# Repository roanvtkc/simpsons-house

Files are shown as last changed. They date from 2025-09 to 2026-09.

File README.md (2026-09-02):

# 🏠 Simpson's House Smart Home Control

A comprehensive smart home automation project that allows you to control LEDs and servo-driven garage and front doors on a Raspberry Pi directly from an iOS Swift Playgrounds app using **MQTT over WebSocket**.







<p align="center">
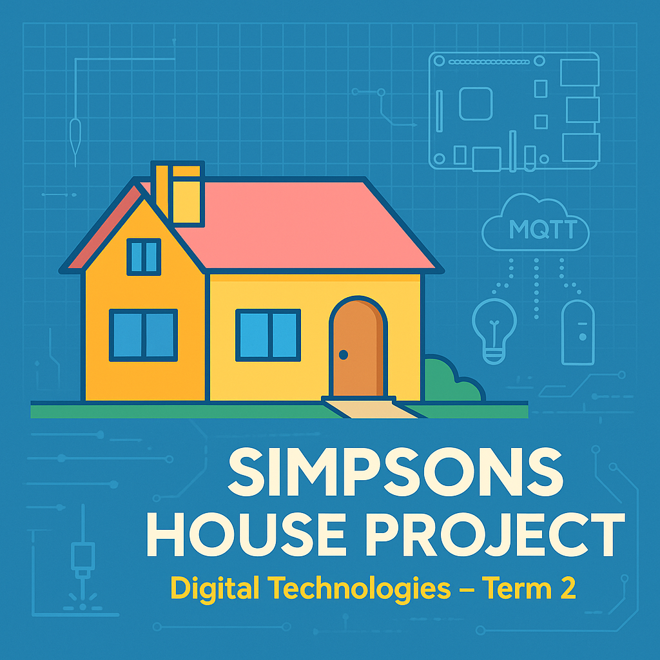
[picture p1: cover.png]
Simpsons House Project
  
</p>

## ✨ Features

- **🏠 Smart Home Control**: Complete home automation system inspired by The Simpsons
- **📱 iOS App**: Beautiful SwiftUI interface built for Swift Playgrounds
- **🌐 MQTT over WebSocket**: Modern, reliable communication protocol
- **🔧 GPIO Control**: Direct hardware control of LEDs and servo motors
- **⚙️ Servo Control**: PWM angle control on both the garage door and the front door
- **📡 Real-time Communication**: Instant response and status feedback
- **🔄 Auto-reconnection**: Robust connection handling with keep-alive pings
- **🕵️ mDNS Discovery**: Automatic network device discovery
- **⚙️ Systemd Integration**: Professional service management

## 📚 Guides

| Guide | What it covers |
|---|---|
| [WIRING_GUIDE.md](WIRING_GUIDE.md) | Identifying each component, breadboard layout, per-device troubleshooting |
| [SERVO_TUNING_GUIDE.md](SERVO_TUNING_GUIDE.md) | Changing how far the doors open, reversing direction, slowing the movement |
| [EXTENSION_GUIDE.md](EXTENSION_GUIDE.md) | Adding your own circuits — the Python side and the Swift app side |
| [TEACHING_GUIDE.md](TEACHING_GUIDE.md) | How a tap on the iPad becomes movement on the Pi |
| [laser-cut/README.md](laser-cut/README.md) | DXF sheets, part chart, layer settings |

## 🔥 Laser-cut plans

Ready-to-import DXF plans are available for two or ten houses on a 450 × 450 mm
bed, plus a ten-house 600 × 450 mm option. See the
[laser-cut guide](laser-cut/README.md) for the sheet files, previews, part chart,
layer settings, and verification results.

## 🏗️ System Architecture

```mermaid
graph TD
    A[iOS Swift Playgrounds App] -->|WebSocket| B[Mosquitto MQTT Broker]
    B -->|TCP| C[Python MQTT Listener]
    C -->|GPIO| D[Raspberry Pi Hardware]
    
    D --> E[💡 Living Room Light<br/>GPIO 17]
    D --> F[🚗 Garage Door Servo<br/>GPIO 27]
    D --> G[🚪 Front Door Servo<br/>GPIO 23]
```

## 📋 Prerequisites

- **Raspberry Pi** running Raspberry Pi OS (32-bit or 64-bit)
- **SSH access** to the Pi (default credentials: `pi`/`tkcraspberry`)
  > 📱 **iPad SSH client**: We recommend [**Secure ShellFish**](https://secureshellfish.app) — no account required, saves sessions, and has a proper iOS keyboard toolbar. Free tier is sufficient for this project.
- **Git installed** on the Pi (will be installed automatically if missing)
- **iOS device** with Swift Playgrounds 4+ or macOS with Xcode 13+
- **Hardware components**: LEDs, resistors, two SG90 servo motors (garage door and front door), breadboard
- **Same network**: Both devices must be on the same local network

## 🚀 Quick Start

### 0. Certificate Installation (Corporate Networks Only)

If you're in a corporate environment with FortiGate firewalls or other SSL inspection systems, `setup.sh` will fail at the "Upgrading pip and setuptools" step with certificate errors like:

```
ERROR: Could not find a version that satisfies the requirement setuptools (from versions: none)
ERROR: No matching distribution found for setuptools
```

with `SSLError(SSLCertVerificationError(... self-signed certificate in certificate chain))` above it in `/tmp/simpsons_house_debug.log`.

**Quick Certificate Installation:**
```bash
# Run the certificate installer from this repo
chmod +x install_ca.sh
./install_ca.sh
```

> **Note:** run the copy in this repo. A copy is also published at
> `http://10.20.1.83:8081/install_ca.sh`, but it may lag behind this one.

The installer adds the FortiGate SSL-inspection CA (`O=Fortinet`) to the system
trust store. Note that `git clone` from GitHub works *without* this — github.com
is exempt from deep inspection — so a successful clone is not evidence that the
certificate is installed. The Python package indexes (pypi.org, piwheels.org,
files.pythonhosted.org) *are* inspected, which is why `setup.sh` fails without it.

### 1. Hardware Setup

#### 🔌 GPIO Pin Layout (BCM Numbering)

```
    3V3  (1) (2)  5V
  GPIO2  (3) (4)  5V
  GPIO3  (5) (6)  GND
  GPIO4  (7) (8)  GPIO14
    GND  (9) (10) GPIO15
 GPIO17 (11) (12) GPIO18
 GPIO27 (13) (14) GND
 GPIO22 (15) (16) GPIO23
    3V3 (17) (18) GPIO24
 GPIO10 (19) (20) GND
  GPIO9 (21) (22) GPIO25
 GPIO11 (23) (24) GPIO8
    GND (25) (26) GPIO7
  GPIO0 (27) (28) GPIO1
  GPIO5 (29) (30) GND
  GPIO6 (31) (32) GPIO12
 GPIO13 (33) (34) GND
 GPIO19 (35) (36) GPIO16
 GPIO26 (37) (38) GPIO20
    GND (39) (40) GPIO21
```

#### 🔧 Wiring

> 📖 **See [WIRING_GUIDE.md](WIRING_GUIDE.md) for the full step-by-step wiring instructions**, including how to identify each component, breadboard layouts, common mistakes, and per-device troubleshooting.

Quick reference — connections at a glance:

**💡 Living Room Light (GPIO 17 → physical pin 11)**
```
Pi GPIO 17 (pin 11) ─── 220Ω resistor ─── LED (+) long leg
                                           LED (−) short leg ─── Pi GND (pin 9)
```
Key fact: the **longer LED leg is +**; it goes toward GPIO 17. The shorter leg goes to GND.

**🚗 Garage Door — Servo Motor (GPIO 27 → physical pin 13)**
```
Pi GPIO 27 (pin 13) ─── Servo SIGNAL wire (orange / yellow / white)
Pi 5V      (pin  2) ─── Servo POWER wire  (red)
Pi GND     (pin 14) ─── Servo GROUND wire (brown / black)
```
Key fact: **red is always power**; if your servo has different colours, red is still VCC.

**🚪 Front Door — Servo Motor (GPIO 23 → physical pin 16)**
```
Pi GPIO 23 (pin 16) ─── Servo SIGNAL wire (orange / yellow / white)
Pi 5V      (pin  4) ─── Servo POWER wire  (red)
Pi GND     (pin  6) ─── Servo GROUND wire (brown / black)
```
Key fact: **red is always power**; if your servo has different colours, red is still VCC.

#### 📋 Component List

| Component | Quantity | Notes |
|---|---|---|
| LED (any color) | 1 | For light indication |
| 220Ω Resistor | 1 | For LED current limiting |
| Servo Motor (SG90) | 2 | One for the garage door, one for the front door |
| Breadboard | 1 | For prototyping |
| Jumper Wires | 15+ | Male-to-female recommended |
| Breadboard Power Module | 1 | Optional, for cleaner power distribution |

#### ⚠️ Safety Notes

- **Two SG90 servos run fine on Pi 5V**: they draw little enough current that no external supply or driver board is needed
- **Never use Pi power for high-current motors**
- **Double-check connections** before powering on
- **Use appropriate resistors** to prevent LED burnout
- **Servo direction**: check which way each servo swings before gluing it into the model
- **Common Ground**: if you do add external power, its GND must be connected to Pi GND

#### 🔍 Pin Verification

Use this command to see the physical pin layout:
```bash
pinout
```

### 2. Raspberry Pi Setup

**Install Git (if needed):**

On your Raspberry Pi, if you see `git: command not found` when trying to clone:
```bash
sudo apt update
sudo apt install -y git
```

**Clone the repository:**
```bash
git clone https://github.com/roanvtkc/simpsons-house.git
cd simpsons-house
```

**Run the automated setup:**
```bash
chmod +x setup.sh
./setup.sh
```

The setup script will:
- ✅ Install all required packages (including git if missing)
- ✅ Configure MQTT with WebSocket support (ports 1883 and 9001)
- ✅ Set up Python environment and GPIO control
- ✅ Create systemd services for automatic startup
- ✅ Configure mDNS for device discovery
- ✅ Test all components

### 3. iOS App Setup

1. **Open Swift Playgrounds** on your iOS device
2. **Create a new playground** or import the provided Swift package
3. **Copy the Simpson's House app code** into your playground
4. **Update the IP address** if needed (the app defaults to `192.168.5.115`)
5. **Run the app** and grant Local Network permissions when prompted

## 🎮 Using the App

### Connection
1. **Tap "Connect to House"** to establish MQTT over WebSocket connection
2. **Wait for "🏠 Simpson's House Connected!"** status
3. **Start controlling your devices!**

### Device Controls
- **💡 Living Room Light**: Toggle the main lighting
- **🚗 Garage Door**: Open and close using the garage servo
  - `OPEN`: Drive the servo to the open angle
  - `CLOSE`: Drive the servo to the closed angle
  - Tuning these angles: see [SERVO_TUNING_GUIDE.md](SERVO_TUNING_GUIDE.md)
- **🚪 Front Door**: Operate the servo-controlled entrance

### Features
- **📊 Real-time status**: See device states instantly
- **📋 Activity logs**: Monitor all commands and responses
- **ℹ️ System info**: View hardware and network configuration
- **🔄 Auto-reconnect**: Automatic connection recovery

## 🛠️ Configuration

### MQTT Topics
| Topic | Description | Commands |
|---|---|---|
| `home/light` | Living room light control | `ON`, `OFF` |
| `home/garage` | garage door servo (GPIO 27) | `OPEN`, `CLOSE` |
| `home/door` | Front door servo | `ON` (open), `OFF` (close) |

### Network Ports
- **1883**: MQTT TCP (standard MQTT clients)
- **9001**: MQTT WebSocket (iOS app)

### Service Management
```bash
# Check status
sudo systemctl status simpsons-house
sudo systemctl status mosquitto

# View logs
sudo journalctl -u simpsons-house -f
sudo journalctl -u mosquitto -f

# Restart services
sudo systemctl restart simpsons-house
sudo systemctl restart mosquitto

# Test MQTT manually
mosquitto_pub -h localhost -t home/light -m ON
mosquitto_pub -h localhost -t home/garage -m OPEN
mosquitto_sub -h localhost -t home/# -v
```

## 🔧 Advanced Configuration

### Custom GPIO Pins
Edit `mqttlistener.py` to change pin assignments:
```python
# GPIO pin assignments (BCM numbering)
LIGHT_PIN        = 17   # Light control
GARAGE_SERVO_PIN = 27   # Garage door servo signal
SERVO_PIN        = 23   # Front door servo signal
```

### Servo Angles
The front door and garage door angles are set in `control_door()` and `control_garage_door()` in `mqttlistener.py`:
```python
angle = 90 if state else 0   # OPEN = 90°, CLOSED = 0°
```

> 📖 **See [SERVO_TUNING_GUIDE.md](SERVO_TUNING_GUIDE.md)** for how to find the right angles for your model, reverse a door's direction, and slow the movement down — plus `servo_calibrate.py`, an interactive tool for jogging each servo to find its angles.

### Network Settings
Update the iOS app host address:
```swift
@StateObject private var mqttClient = SimpsonsHouseMQTTClient(host: "YOUR_PI_IP_ADDRESS")
```

## 🧪 Testing & Verification

### Test GPIO Pins Before MQTT Setup

**Run the built-in hardware test:**
```bash
cd ~/simpsons-house
python3 gpio_test.py
```

It walks the light and both servos in turn. If you want to try a single servo by
hand, this is the minimum:
```python
#!/usr/bin/env python3
import RPi.GPIO as GPIO
import time

GARAGE_SERVO_PIN = 27          # use 23 for the front door servo

GPIO.setmode(GPIO.BCM)
GPIO.setup(GARAGE_SERVO_PIN, GPIO.OUT)
pwm = GPIO.PWM(GARAGE_SERVO_PIN, 50)   # 50 Hz is the hobby-servo standard
pwm.start(0)

try:
    for angle in (0, 90, 0):
        pwm.ChangeDutyCycle((angle / 180.0) * 10 + 2)   # 0° → 2%, 180° → 12%
        time.sleep(0.8)                                  # let the servo travel
        pwm.ChangeDutyCycle(0)                           # stop pulsing, avoid jitter
        time.sleep(0.5)
finally:
    pwm.stop()
    GPIO.cleanup()
```

### Expected Results:
- **💡 Light LED**: Should turn ON for 2 seconds, then OFF
- **🚗 Garage door servo**: Should swing from 0° (closed) to 90° (open) and back
- **🚪 Front door servo**: Should move from 0° to 90° and back to 0°

### Verify Services
```bash
# Check MQTT broker
sudo systemctl status mosquitto

# Check listening ports (should show both 1883 and 9001)
sudo netstat -tlnp | grep -E "(1883|9001)"

# Test MQTT broker
mosquitto_pub -h localhost -t test/message -m "Hello Simpson's House"
mosquitto_sub -h localhost -t test/# -v

# Check mDNS discovery
avahi-browse -rt _mqtt._tcp
```

### Test Device Control
```bash
# Test individual devices
mosquitto_pub -h localhost -t home/light -m ON
mosquitto_pub -h localhost -t home/garage -m OPEN   # Open garage door
mosquitto_pub -h localhost -t home/garage -m CLOSE  # Close garage door
mosquitto_pub -h localhost -t home/door -m ON   # Servo open
```

## 🐛 Troubleshooting

<details>
<summary><strong>Servo Motor Issues</strong></summary>

**Servo doesn't move:**
- Check the signal wire is on the right pin — GPIO 27 (pin 13) for the garage, GPIO 23 (pin 16) for the front door
- Red wire must be on Pi 5V, not 3.3V — a servo on 3.3V often twitches but won't hold
- Ensure the servo GND is connected to Pi GND
- Confirm nothing else is holding the pin: `sudo fuser /dev/gpiomem`

**Servo jitters or hums when idle:**
- Expected if pulses keep being sent. The code calls `ChangeDutyCycle(0)` after each move to stop this — check it isn't commented out
- Both servos on Pi 5V can brown out the Pi if they move at the same instant under load; add an external 5V supply (GND common with the Pi) if so

**Servo moves the wrong way:**
- Swap the angles in `control_garage_door()` / `control_door()` — the code maps OPEN = 90°, CLOSED = 0°
- Or remount the horn 90° round on the spline

**Servo doesn't reach full travel:**
- SG90s vary; adjust the 2%–12% duty range in `set_servo_angle()` to suit your unit
- Check the door isn't binding on the model before blaming the servo
</details>

<details>
<summary><strong>GPIO & Hardware Issues</strong></summary>

**Check GPIO status:**
```bash
# See pin layout
pinout

# Check what's using GPIO pins
sudo fuser /dev/gpiomem
```

**Manual servo testing:**

A servo needs a continuous 50 Hz pulse train, so it cannot be driven from the
shell the way an LED can — use the Python snippet in
[Testing & Verification](#-testing--verification) above, or `gpio_test.py`.

**Common servo wiring issues:**
- Signal on the wrong pin: garage is GPIO 27 (pin 13), front door is GPIO 23 (pin 16)
- Power on 3.3V instead of 5V — always use a 5V pin for the red wire
- Missing common ground between servo and Pi
- Connector reversed: check the wire colours, not the plug orientation — red is always power
</details>

### Log Locations
- **Setup logs**: `/tmp/simpsons_house_setup.log`
- **MQTT listener**: `sudo journalctl -u simpsons-house -f`
- **Mosquitto broker**: `/var/log/mosquitto/mosquitto.log`
- **System logs**: `sudo journalctl -f`

## 🔒 Security Considerations

> ⚠️ **Important**: This project uses `allow_anonymous true` for simplicity. For production use:

- Enable MQTT authentication with username/password
- Use TLS/SSL encryption for MQTT connections
- Configure firewall rules to limit access
- Regular security updates for all components
- Consider VPN access for remote control

## 📁 Project Structure

```
simpsons-house/
├── 📄 README.md                    # This file
├── 📖 SERVO_TUNING_GUIDE.md         # Adjusting door angles, direction and speed
├── 📖 EXTENSION_GUIDE.md            # Adding your own circuits (Python + Swift)
├── 🔧 setup.sh                     # Automated setup script
├── 🐍 mqttlistener.py               # Python MQTT listener with servo control
├── 🔐 install_ca.sh                # FortiGate certificate installer
├── 🧪 gpio_test.py                  # Hardware test: light + both servos
├── 🎛️  servo_calibrate.py            # Interactive servo angle finder
├── 📁 extensions/                   # Optional extension hardware
│   └── 🧪 stepper_test.py           # Stepper motor test (extension only)
├── 📱 ios-app/                     # Swift Playgrounds app code
│   └── ContentView.swift
├── 📋 systemd/                     # Systemd service files
│   └── simpsons-house.service
└── 📊 docs/                        # Additional documentation
    ├── hardware-setup.md
    ├── troubleshooting.md
    └── api-reference.md
```

## 🤝 Contributing

We welcome contributions! Please see our [Contributing Guide](CONTRIBUTING.md) for details.

### Development Setup
1. **Fork the repository**
2. **Create a feature branch**: `git checkout -b feature/amazing-feature`
3. **Commit changes**: `git commit -m 'Add amazing feature'`
4. **Push to branch**: `git push origin feature/amazing-feature`
5. **Open a Pull Request**

## 📄 License

This project is licensed under the MIT License - see the [LICENSE](LICENSE) file for details.

## 🎯 Roadmap

### Upcoming Features
- [ ] **Temperature sensors** and climate control
- [ ] **Motion detection** and security features
- [ ] **Voice control** integration (Siri Shortcuts)
- [ ] **Web dashboard** for browser control

> **Motors are extension work, not core.** DC motors, steppers, speed control and
> direction reversal all need external power and a driver board, so they sit
> outside the base build. See [EXTENSION_GUIDE.md](EXTENSION_GUIDE.md).

### Version History
- **v3.3** - Garage door moved from a 28BYJ-48 stepper + ULN2003 to an SG90 servo on GPIO 27
- **v3.1** - ULN2003 motor driver integration, improved motor control
- **v3.0** - MQTT over WebSocket support, systemd integration
- **v2.0** - Basic MQTT control with GPIO
- **v1.0** - Initial HTTP-based control system

## 📞 Support

### Getting Help
- 📖 Check the [Documentation](docs/)
- 🐛 [Report Issues](https://github.com/roanvtkc/simpsons-house/issues)
- 💬 [Discussions](https://github.com/roanvtkc/simpsons-house/discussions)
- ❓ [FAQ](docs/faq.md)

### Community
- 🌟 **Star this repo** if you find it useful!
- 🐦 Follow updates on Twitter: [@SimpsonsHousePi](https://twitter.com/simpsonshousepi)
- 💡 Share your builds and modifications

---

**Made with ❤️ for smart home enthusiasts and Simpsons fans**

For support and questions, please [open an issue](https://github.com/roanvtkc/simpsons-house/issues) or check our [troubleshooting guide](docs/troubleshooting.md).

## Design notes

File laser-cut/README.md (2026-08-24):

# Laser-cut enclosure

Cut files for the physical Simpsons House model that the Raspberry Pi hardware
goes into.

## Available layouts

| Folder | Bed/stock size | Houses | Sheets | Average utilisation |
|---|---:|---:|---:|---:|
| `sheets-450x450-two-houses/` | 450 × 450 mm | 2 | 3 | 83.6% |
| `sheets-450x450-ten-houses/` | 450 × 450 mm | 10 | 15 | 83.6% |
| `sheets-600x450/` | 600 × 450 mm | 10 | 11 | 85.5% |

The two-house layout uses the theoretical minimum of three 450 × 450 sheets:
the combined reserved part area will not fit on two sheets. The ten-house
450 × 450 layout likewise cannot fit on fewer than 15 sheets with the specified
3 mm part spacing and 5 mm border.

## What to send to the laser

For two houses on the 450 × 450 mm RedSail, send
`sheets-450x450-two-houses/sheet-01.dxf` … `sheet-03.dxf`. The files are in
millimetres.

For ten houses on the same 450 × 450 bed, send
`sheets-450x450-ten-houses/sheet-01.dxf` … `sheet-15.dxf`. If 600 × 450 stock
is available, the more compact option is `sheets-600x450/sheet-01.dxf` …
`sheet-11.dxf`.

Each file has three layers:

| Layer | What to do with it |
|---|---|
| `CUT` | Cut this. Part outlines plus the LED and access-port holes. |
| `ENGRAVE` | Part numbers, single-stroke. Run as a light score, or switch off. |
| `SHEET` | Reference rectangle matching the selected sheet size. **Not for cutting** — switch off or delete. |

**46 of 52 parts carry a number.** Each number sits on material only, at least
0.35 mm clear of every cut and score line, turned 90° where a narrow frame band
is the only place it fits. The six that are blank (31, 32, 40–43) are window
inserts whose bars are 2.5 mm wide — too narrow for a readable number. Each
belongs to a set of identical parts, so they are interchangeable; identify them
from `PART-CHART.pdf`.

## Reference

| File | Contents |
|---|---|
| `sheets-*/CUT-PLAN.txt` | Part library with sizes, and what sits on each sheet for that layout |
| `PART-CHART.pdf` | Every part drawn and numbered — use it to identify cut pieces |
| `ASSEMBLY-MAPPING.md` | Proposed mapping from engraved numbers to the assembly-instruction step numbers, graded by confidence |
| `sheets-*/nest-preview.png` | All sheets in that layout at a glance |
| `source/` | The original Shapr3D DXF export |

## LED and access-port cutouts

The original six circular cutouts are restored at their authored locations on
every house. They had appeared outside the parts because DXF stores circle
centres in object coordinates and this Shapr3D export uses a reversed normal;
the generator now converts them to world coordinates before grouping and
nesting the panels.

| Part | Circular cuts per house | Purpose |
|---:|---|---|
| 01 | 1 × 22.361 mm | Access port |
| 02 | 1 × 50.000 mm | Access port |
| 06 | 1 × 5.000 mm | LED hole |
| 08 | 1 × 36.056 mm, 2 × 5.000 mm | Access port and two LED holes |

Each generated `CUT-PLAN.txt` records the exact local position of these holes.
`PART-CHART.pdf` shows which panels contain them.

## Two-house 450 × 450 results

- 52 parts per house, 104 parts across 3 sheets
- 83.6% average sheet utilisation: 88.8%, 87.0%, and 75.0%
- 3 mm between part bounding boxes and a 5 mm border
- All 4,118 cut entities verified present, including 12 circular cutouts; no part overlaps; every part inside the margin
- All 1,292 engrave strokes verified on material and at least 0.35 mm from a cut line

## Ten-house 450 × 450 results

- 52 parts per house, 520 parts across 15 sheets
- 83.6% average sheet utilisation
- 3 mm between part bounding boxes and a 5 mm border
- All 20,590 cut entities verified present, including 60 circular cutouts
- All 6,460 engrave strokes verified on material and at least 0.35 mm from a cut line
- No part overlaps; every part is inside the margin

## Ten-house 600 × 450 results

- 52 parts per house (40 distinct shapes), 520 parts over 11 sheets
- 85.5% average sheet utilisation
- 3 mm between parts, 5 mm border
- All 20,590 cut entities verified present, including 60 circular cutouts; no part overlaps; every part inside the margin
- All 6,460 engrave strokes verified on material and at least 0.35 mm from a cut line

## Known source-export issue

There are **27 open-contour gaps**, largest 0.090 mm. They are recorded in each
`CUT-PLAN.txt` and are not changed in the cut files. Most laser software cuts
open paths fine; if yours needs closed contours, weld on import with a 0.1 mm
tolerance.

Note also that the 3 mm spacing is *between parts*, not kerf compensation — cut
paths are the original geometry, so parts finish about one kerf undersize. Check
a test joint before committing a full run of material.

## Regenerating

```bash
cd laser-cut/src
pip install -r requirements.txt
python nest.py --sheet-w 600 --sheet-h 450 --outdir ../sheets-600x450
python nest.py --copies 2 --sheet-w 450 --sheet-h 450 --outdir ../sheets-450x450-two-houses
python nest.py --copies 10 --sheet-w 450 --sheet-h 450 --outdir ../sheets-450x450-ten-houses
python chart.py --out ../PART-CHART.svg
```

`nest.py` reads `../source/Simpsons House with precuts.dxf`; override with
`SIMPSONS_DXF=/path/to/other.dxf`.

Useful flags: `--copies N` (default 10), `--gap`, `--margin`, `--no-rotate`,
`--no-engrave`, `--keep-strays` (include truly isolated circles that do not
belong to a part).

| Script | Role |
|---|---|
| `parts.py` | Reads the DXF, groups loose lines into parts by endpoint connectivity, absorbs holes |
| `labels.py` | Builds each part's solid region and finds where a number fits |
| `strokefont.py` | Single-stroke digits |
| `verify_labels.py` | Independent check that a number is on material — ray casting against the raw cut segments |
| `nest.py` | Packs parts onto sheets, verifies, writes DXFs and the cut plan |
| `check_sheets.py` | End-to-end check of the written DXFs (`python check_sheets.py ../sheets-450x450-two-houses`) |
| `chart.py` | Renders the part identification chart |
| `shapes.py` | Reports which parts are duplicates |

The source DXF has 2,053 loose `LINE` entities rather than closed polylines,
plus the six `CIRCLE` cutouts. Part identity is reconstructed from endpoint
connectivity and the contained circles are absorbed into their panels.
`nest.py` self-checks on every run: no part overlaps, everything is inside the
margin, every engraved number lands on material, and the line/circle entity
counts round-trip through the written files.

Engrave placement is checked **twice, by two independent routes**. `labels.py`
decides where a number goes from the part's solid region; `verify_labels.py`
then re-tests it by ray casting against the raw cut segments, never touching
that solid. This matters: an earlier version checked the text against the same
solid that positioned it, so when the solid was wrong the numbers landed in
window openings and the check still passed. `check_sheets.py` closes the loop by
re-deriving the material from the finished DXFs, which is the only check that
can catch a bad transform on a rotated copy.

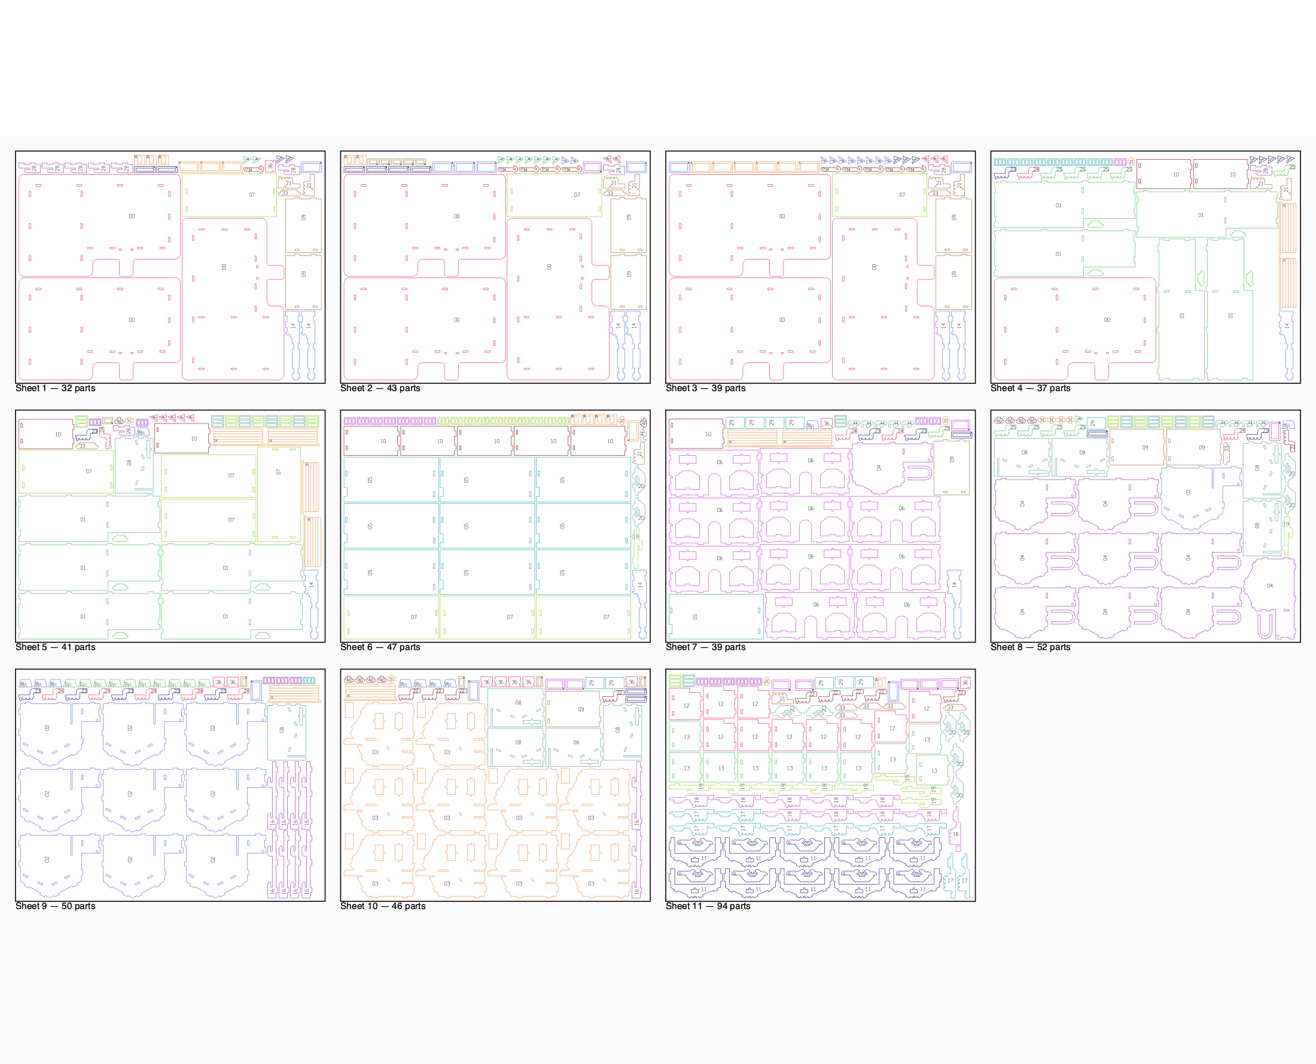
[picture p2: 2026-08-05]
laser-cut/nest-preview.png

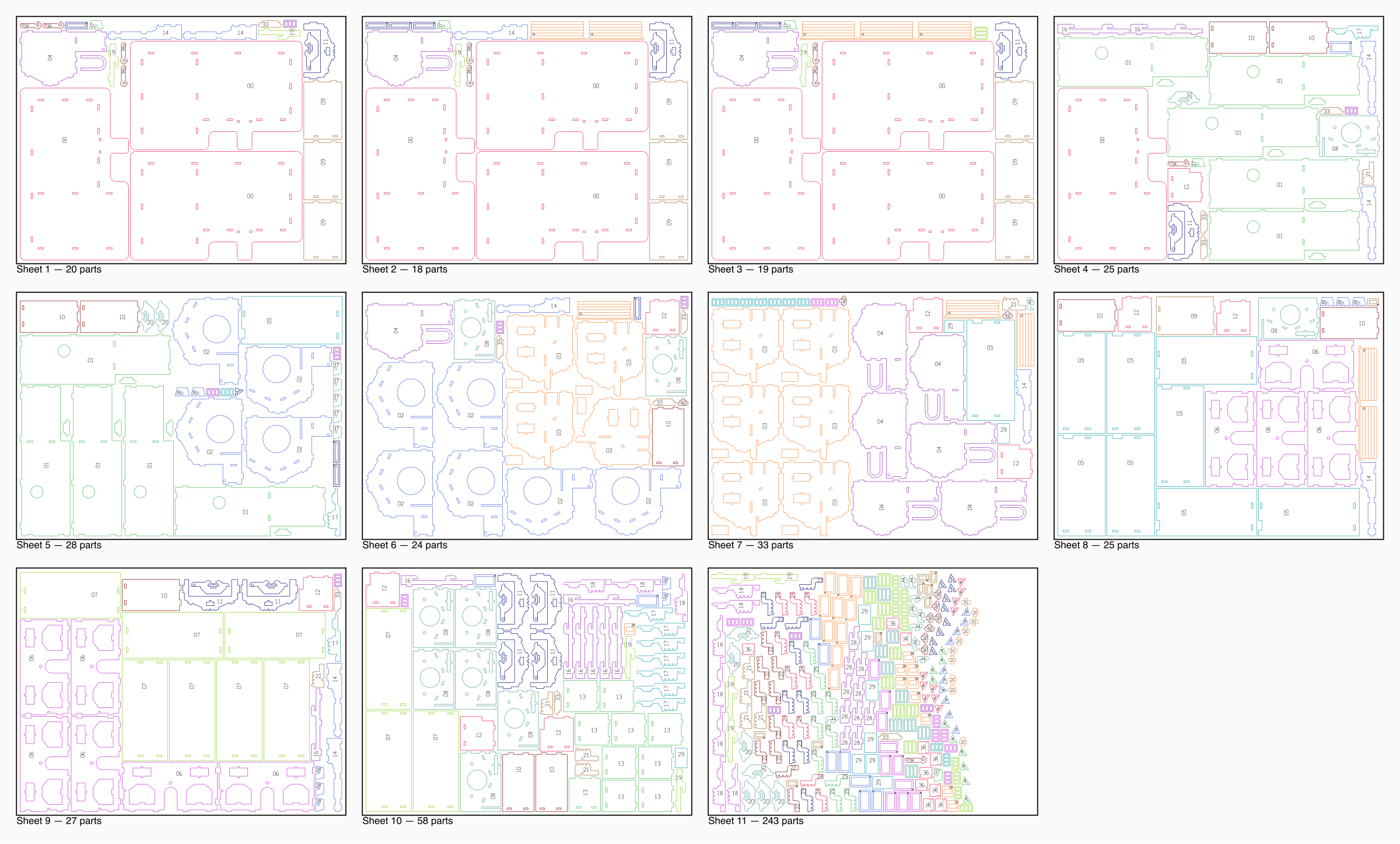
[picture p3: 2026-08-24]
laser-cut/sheets-600x450/nest-preview.png

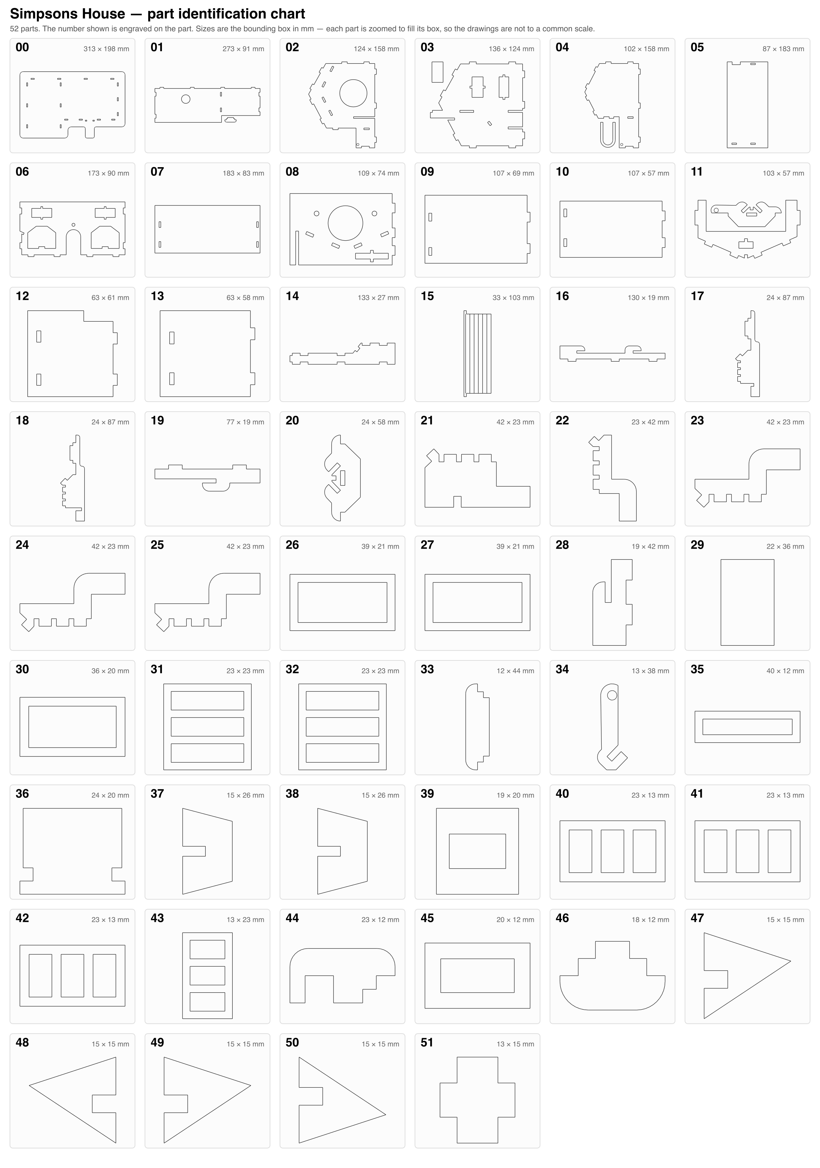
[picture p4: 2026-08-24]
laser-cut/PART-CHART.png

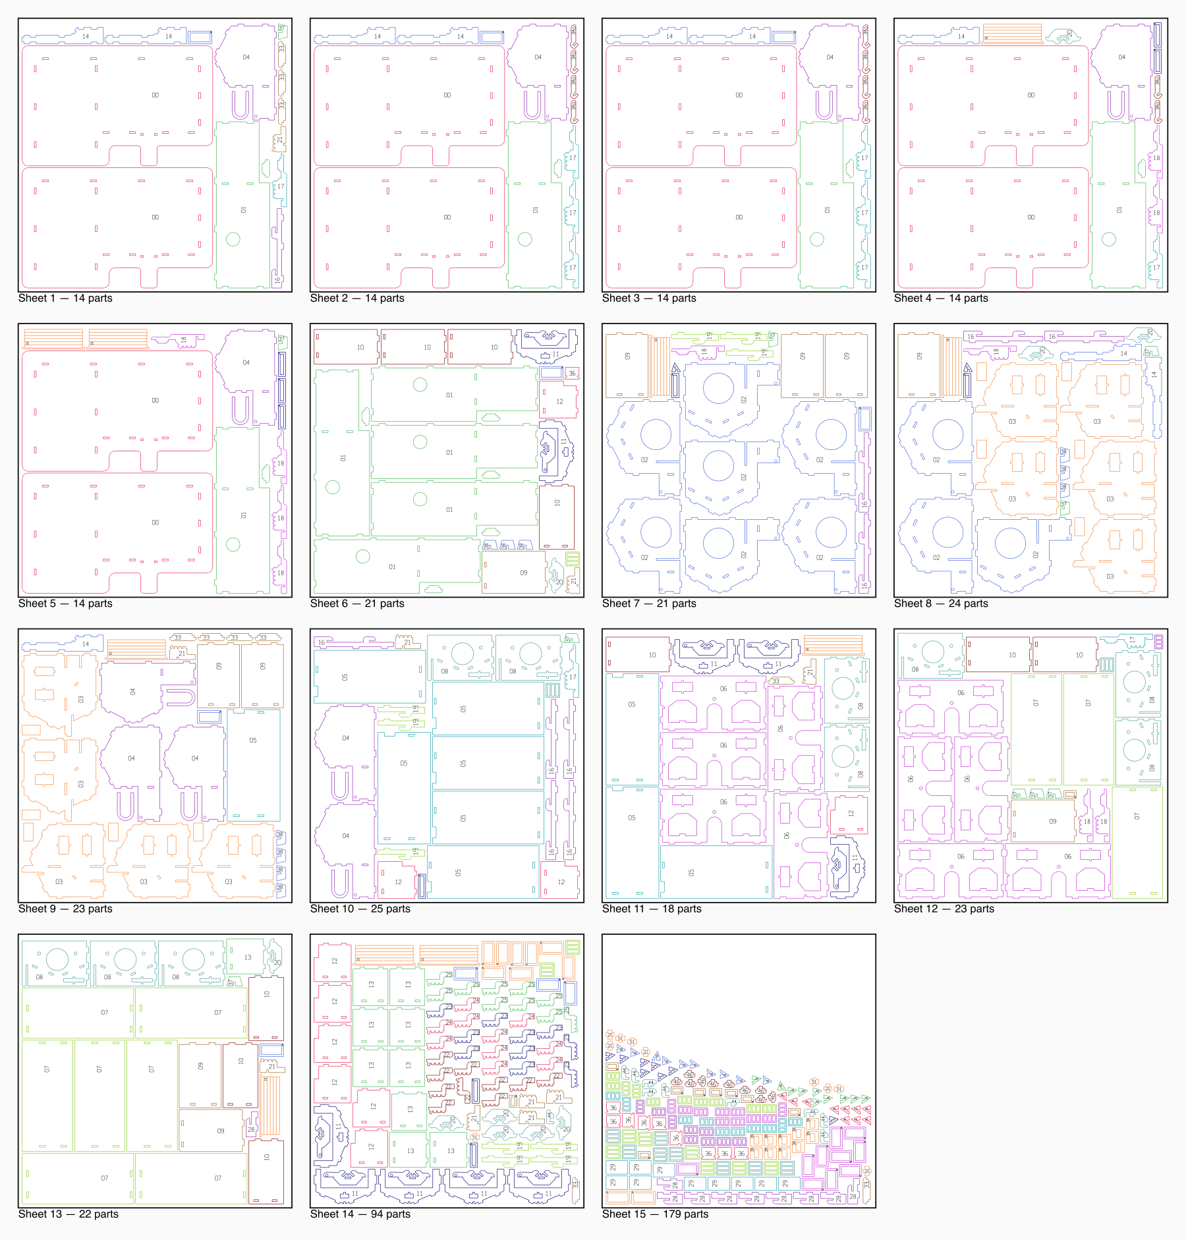
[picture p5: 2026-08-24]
laser-cut/sheets-450x450-ten-houses/nest-preview.png

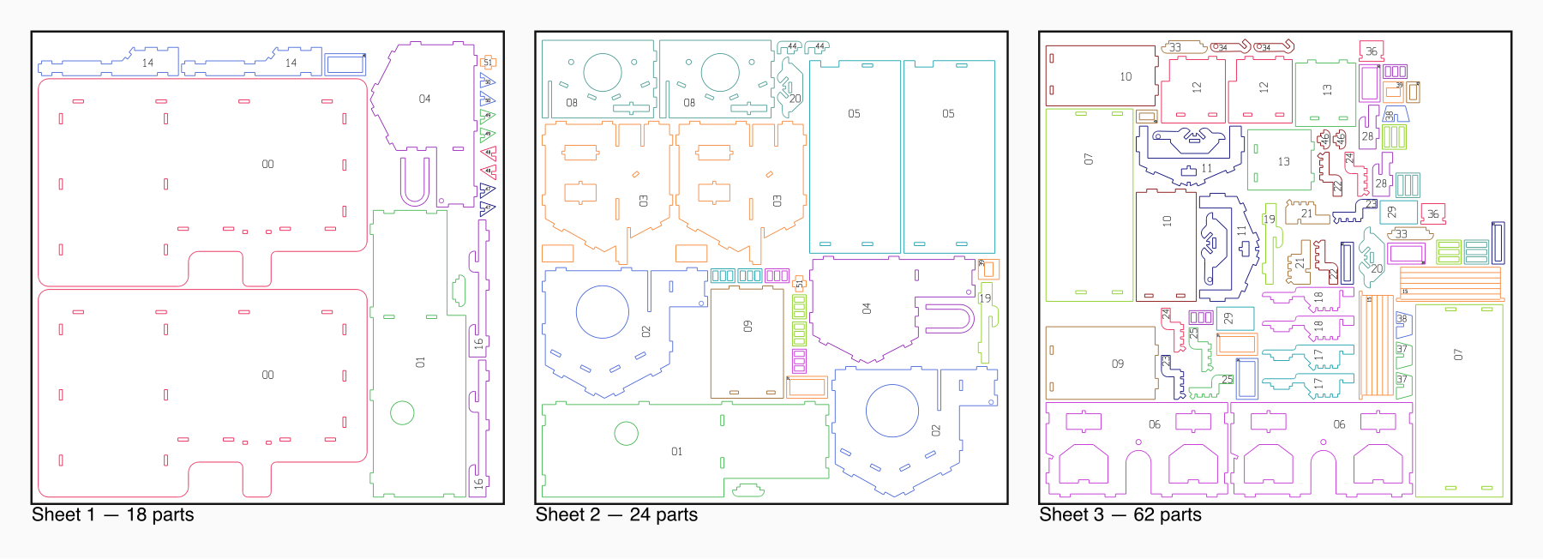
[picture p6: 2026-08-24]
laser-cut/sheets-450x450-two-houses/nest-preview.png

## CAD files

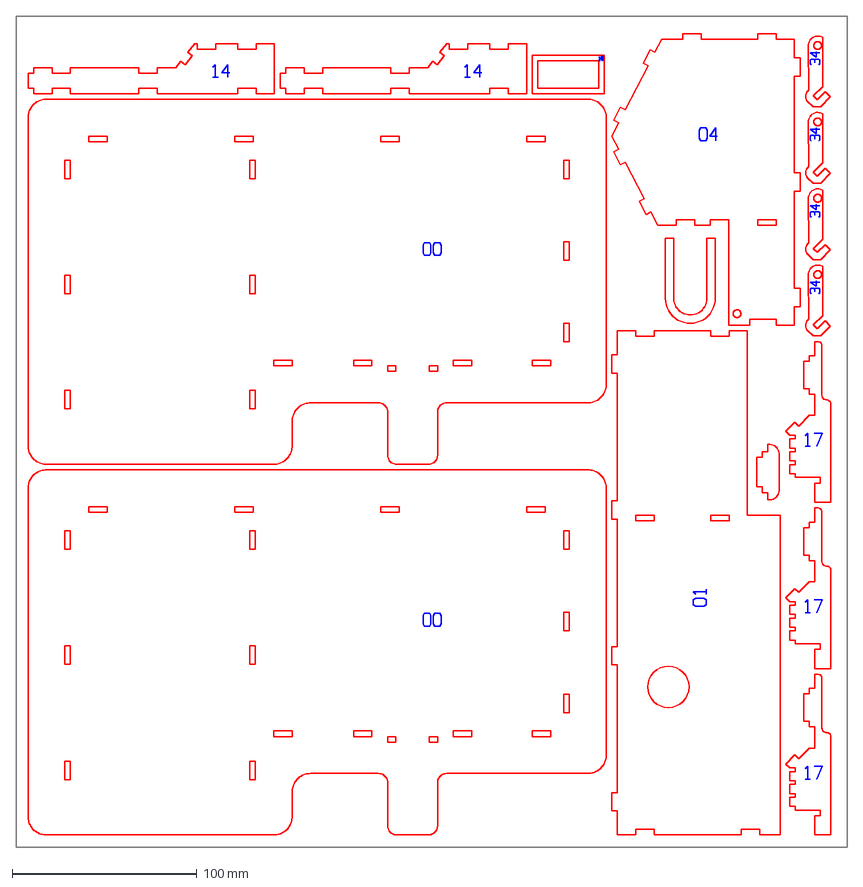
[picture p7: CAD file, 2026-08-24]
laser-cut/sheets-450x450-ten-houses/sheet-02.dxf
450.0 x 450.0 mm

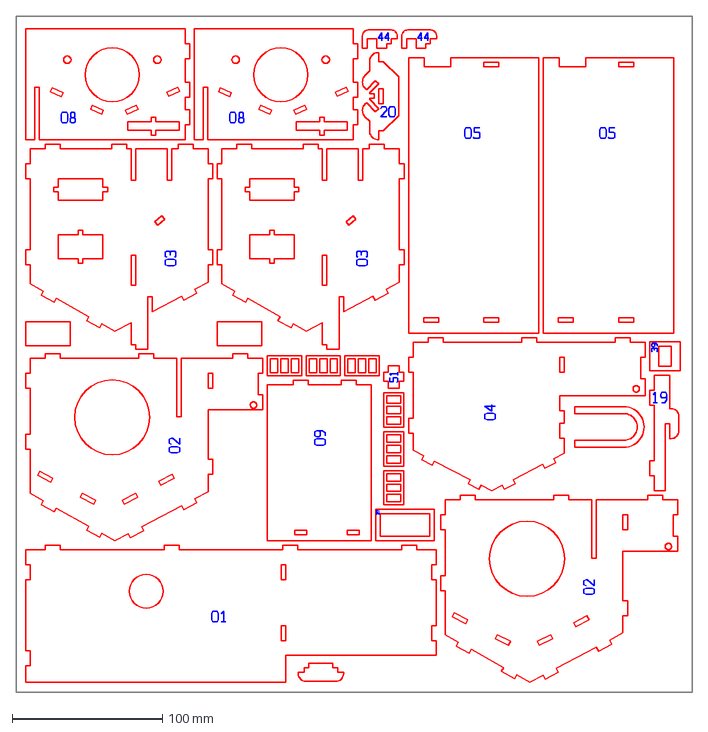
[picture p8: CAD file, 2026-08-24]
laser-cut/sheets-450x450-two-houses/sheet-02.dxf
450.0 x 450.0 mm

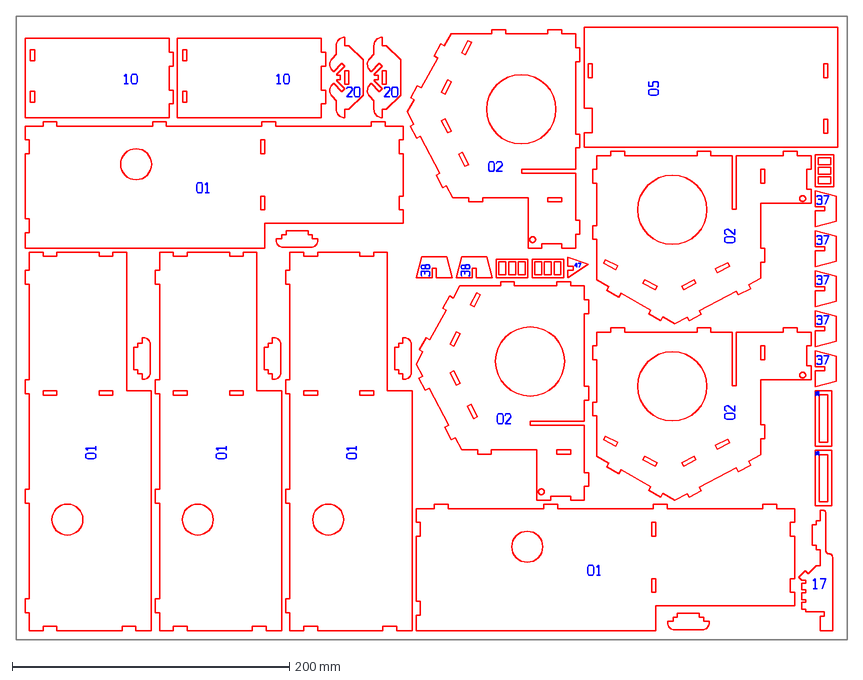
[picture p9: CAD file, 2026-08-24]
laser-cut/sheets-600x450/sheet-05.dxf
600.0 x 450.0 mm

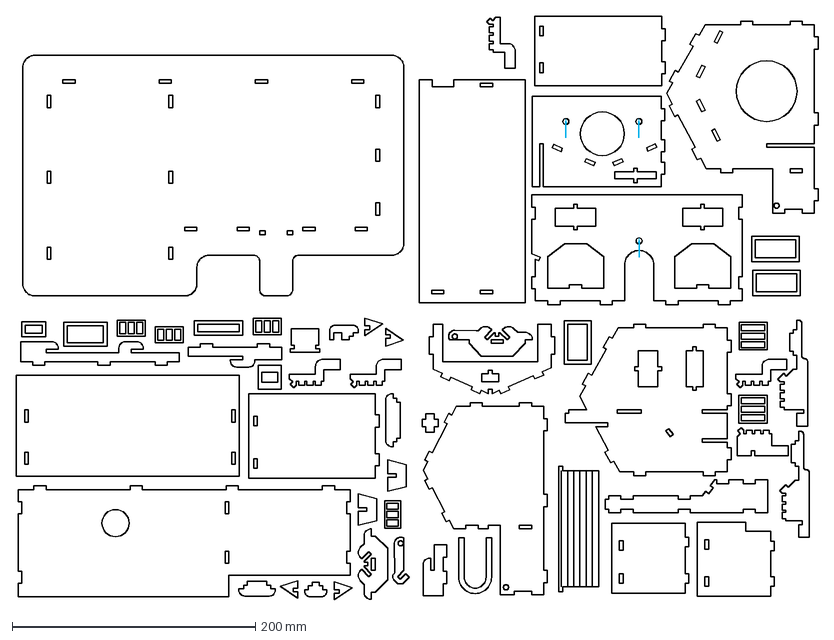
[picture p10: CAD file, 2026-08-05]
laser-cut/source/Simpsons House with precuts.dxf
659.1 x 479.4 mm

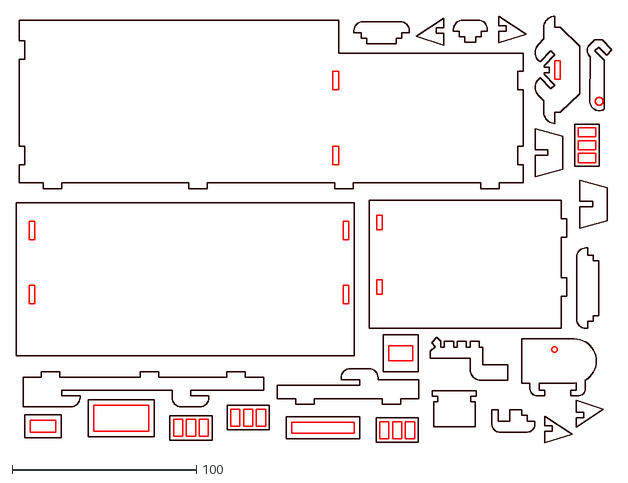
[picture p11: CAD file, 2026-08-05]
Simpson House DXF Files/Simpsons_house_02.dxf
323.0 x 231.4

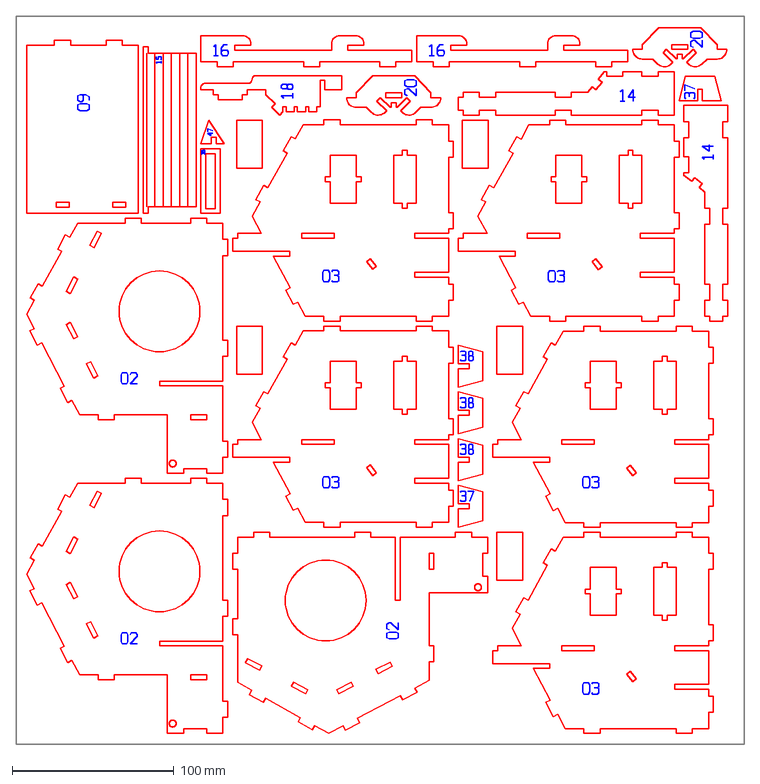
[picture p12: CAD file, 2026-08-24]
laser-cut/sheets-450x450-ten-houses/sheet-08.dxf
450.0 x 450.0 mm

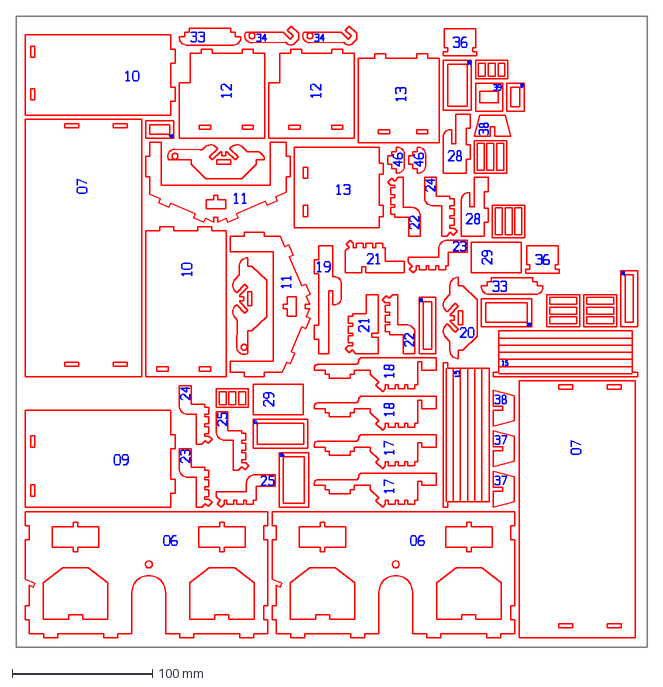
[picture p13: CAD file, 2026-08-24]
laser-cut/sheets-450x450-two-houses/sheet-03.dxf
450.0 x 450.0 mm

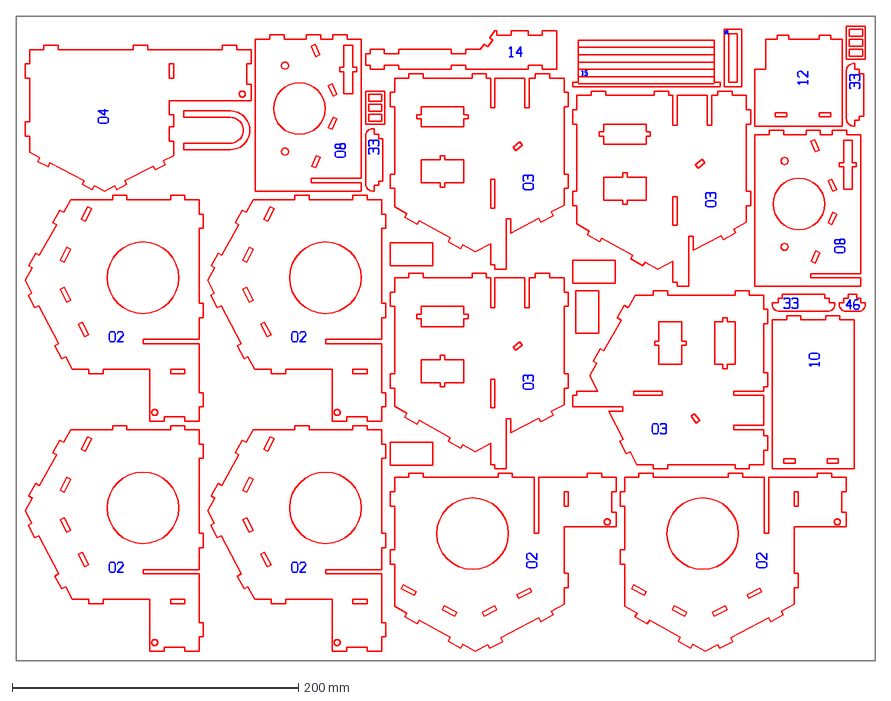
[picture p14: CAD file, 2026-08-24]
laser-cut/sheets-600x450/sheet-06.dxf
600.0 x 450.0 mm

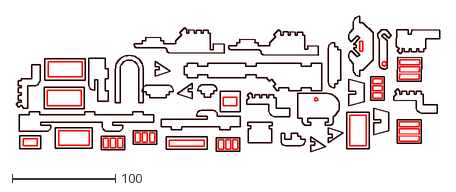
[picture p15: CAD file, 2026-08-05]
Simpson House DXF Files/Simpsons_house_small pieces.dxf
411.0 x 131.2

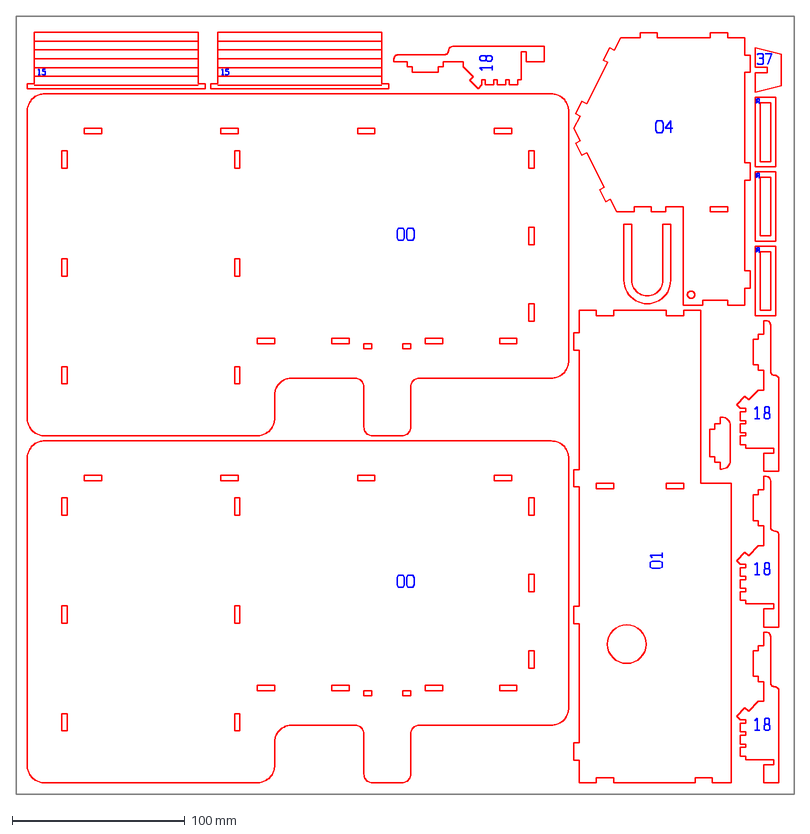
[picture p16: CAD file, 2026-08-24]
laser-cut/sheets-450x450-ten-houses/sheet-05.dxf
450.0 x 450.0 mm

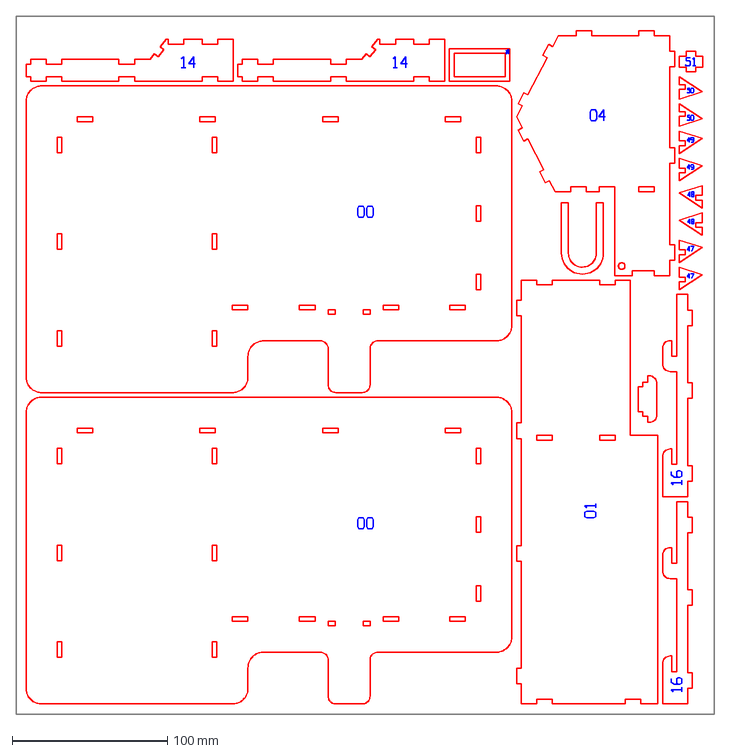
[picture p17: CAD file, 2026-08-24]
laser-cut/sheets-450x450-two-houses/sheet-01.dxf
450.0 x 450.0 mm

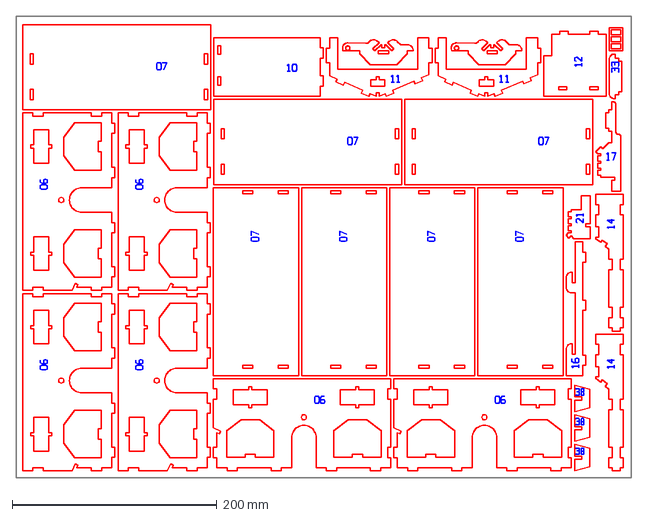
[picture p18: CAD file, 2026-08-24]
laser-cut/sheets-600x450/sheet-09.dxf
600.0 x 450.0 mm

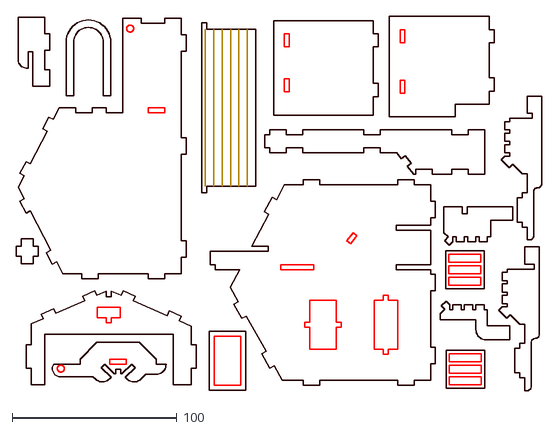
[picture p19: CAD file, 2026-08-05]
Simpson House DXF Files/Simpsons_house_01.dxf
318.3 x 226.8

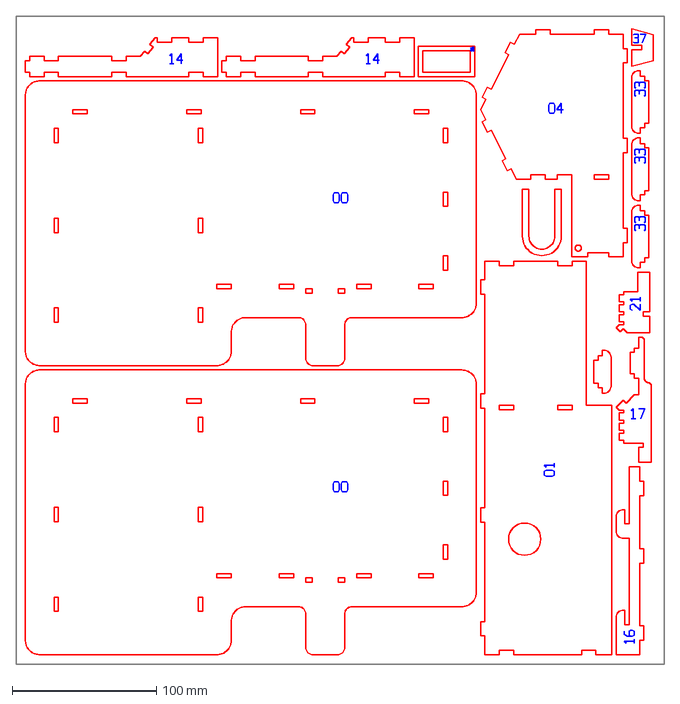
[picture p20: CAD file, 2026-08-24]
laser-cut/sheets-450x450-ten-houses/sheet-01.dxf
450.0 x 450.0 mm

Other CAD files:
Simpson House DXF Files/Whole Simpsons House v1.dxf
laser-cut/sheets-600x450/sheet-02.dxf
Simpson House DXF Files/Simpsons_house_04.dxf
laser-cut/sheets-450x450-ten-houses/sheet-15.dxf
Simpson House DXF Files/Simpsons House with precuts.dxf
Simpson House DXF Files/Simpsons_house_03.dxf
Simpson House DXF Files/Simpsons_house_small pieces.dwg
laser-cut/sheets-450x450-ten-houses/sheet-03.dxf
laser-cut/sheets-450x450-ten-houses/sheet-04.dxf
laser-cut/sheets-450x450-ten-houses/sheet-06.dxf
laser-cut/sheets-450x450-ten-houses/sheet-07.dxf
laser-cut/sheets-450x450-ten-houses/sheet-09.dxf
laser-cut/sheets-450x450-ten-houses/sheet-10.dxf
laser-cut/sheets-450x450-ten-houses/sheet-11.dxf
laser-cut/sheets-450x450-ten-houses/sheet-12.dxf
laser-cut/sheets-450x450-ten-houses/sheet-13.dxf
laser-cut/sheets-450x450-ten-houses/sheet-14.dxf
laser-cut/sheets-600x450/sheet-01.dxf
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

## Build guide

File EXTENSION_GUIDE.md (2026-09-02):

# Extension Guide — Adding Your Own Circuits

For students who have the light, garage door and front door working, and want
to add something of their own.

You will add one new device end to end: a physical component on the
breadboard, a control function on the Raspberry Pi, and a button in the iPad
app.

---

## Safety first

- **Low voltage only.** Everything in this project runs on 3.3V or 5V from the
  Pi. Never wire anything to mains power. If your idea needs mains, it does not
  go in this project.
- **Power the Pi off** before adding or moving any wire.
- **Check the current.** A single GPIO pin can supply about 16 mA safely, and
  the whole chip about 50 mA total. An LED is fine. A motor is not — it needs
  its own power supply and a transistor or driver board.
- If anything gets hot or smells, unplug it immediately.

---

## How a device is wired into the software

Every device already in this project exists in **eight places**. Adding one
means repeating that same pattern. Nothing here is clever — it is the same
five lines copied and renamed.

```
   iPad app                                Raspberry Pi
   ─────────                               ────────────
   1. DeviceStates property   ──┐
   2. topics list               │   MQTT     ┌── 5. TOPIC_ constant
   3. toggle function        ───┼──────────▶ ├── 6. device_states entry
   4. card in the grid          │            ├── 7. control function
                                │            └── 8. branch in on_message()
                                │                     │
                                └──── status ◀────────┘
```

Plus one on the hardware side: **the GPIO pin constant**.

---

## Worked example — adding a doorbell buzzer

We will add an active buzzer on **GPIO 5** (physical pin 29), controlled by a
new topic `home/buzzer`.

Pick a different pin if GPIO 5 is already used in your build. Free pins in this
project include 5, 6, 12, 13, 16, 19, 20, 21, 26. Already taken: **17** (light),
**27** (garage servo), **23** (front door servo).

### Step 1 — Wire the buzzer

An **active** buzzer makes a sound whenever it has power. A **passive** buzzer
needs a PWM signal and will stay silent on a plain HIGH — check which one you
have.

```
Pi GPIO 5 (pin 29) ─── Buzzer (+) long leg
                       Buzzer (−) short leg ─── Pi GND (pin 30)
```

Power the Pi back on before continuing.

---

### Step 2 — Python: add the pin

In `mqttlistener.py`, **Section 1: Configuration**, next to the other pins:

```python
LIGHT_PIN        = 17   # Living Room Light
GARAGE_SERVO_PIN = 27   # Garage Door Servo signal wire
SERVO_PIN        = 23   # Front Door Servo signal wire
BUZZER_PIN       = 5    # Doorbell buzzer          <-- NEW
```

### Step 3 — Python: add the topic

A few lines below, with the other topics:

```python
TOPIC_LIGHT  = "home/light"
TOPIC_GARAGE = "home/garage"
TOPIC_DOOR   = "home/door"
TOPIC_BUZZER = "home/buzzer"    # <-- NEW
```

### Step 4 — Python: add it to the state tracker

```python
device_states = {
    "light":  False,
    "garage": False,
    "door":   False,
    "buzzer": False,    # <-- NEW
}
```

> **The key name matters.** `on_message()` works it out from the topic with
> `topic.split('/')[-1]`, so `home/buzzer` becomes `"buzzer"`. The dictionary
> key must match the last word of the topic exactly, or the status update back
> to the iPad will fail.

### Step 5 — Python: set the pin up

In `setup_gpio()`, alongside the other `GPIO.setup()` calls:

```python
GPIO.setup(BUZZER_PIN, GPIO.OUT, initial=GPIO.LOW)    # <-- NEW
```

`initial=GPIO.LOW` means the buzzer starts silent. Without it the pin state is
undefined and your buzzer may shriek the moment the service starts.

### Step 6 — Python: subscribe to the topic

In `on_connect()`, add your topic to the list the Pi listens on:

```python
for topic in [TOPIC_LIGHT, TOPIC_GARAGE, TOPIC_DOOR, TOPIC_BUZZER]:
```

**This is the step people forget.** Miss it and everything else looks correct,
but the Pi never hears the message.

### Step 7 — Python: write the control function

In **Section 5: Device Control Functions**, copy `control_light()` and rename it:

```python
def control_buzzer(state: bool) -> bool:
    """Turn the doorbell buzzer on or off."""
    try:
        GPIO.output(BUZZER_PIN, GPIO.HIGH if state else GPIO.LOW)
        logger.info(f"🔔 Buzzer → {'ON' if state else 'OFF'}")
        return True
    except Exception as e:
        logger.error(f"❌ Buzzer control error: {e}")
        return False
```

### Step 8 — Python: route the message

In `on_message()`, add a branch alongside the others, **before** the final
`else`:

```python
elif topic == TOPIC_BUZZER:
    valid_commands = {"ON": True, "OFF": False}
    device_name    = "Doorbell Buzzer"
    command_state  = valid_commands.get(payload)
    if command_state is None:
        publish_error(topic, f"Invalid command: {payload}. Use ON or OFF.")
        return
    success = control_buzzer(command_state)
```

### Step 9 — Test the Pi on its own

Before touching the app, prove the Python half works. Restart the service and
send a message by hand from a second terminal:

```bash
sudo systemctl restart simpsons-house.service
mosquitto_pub -h localhost -t home/buzzer -m "ON"
mosquitto_pub -h localhost -t home/buzzer -m "OFF"
```

Watch the log while you do it:

```bash
journalctl -u simpsons-house.service -f
```

If the buzzer sounds, the whole Pi side is finished. **Do not move on until
this works** — debugging Python and Swift at the same time is much harder.

---

## Now the iPad app

### Step 10 — Swift: add the state property

Open `Models.swift`. This file is normally marked *do not edit* — adding a
device is the one time you are meant to.

```swift
class DeviceStates: ObservableObject {
    @Published var lightOn = false
    @Published var garageOpen = false
    @Published var doorOpen = false
    @Published var buzzerOn = false    // <-- NEW
}
```

### Step 11 — Swift: add the topic

In `MQTTClient.swift`, in the `topics` list near the top:

```swift
private let topics = [
    "home/light",   // GPIO 17 - Living Room Light
    "home/garage",  // GPIO 27 - Garage Door Servo
    "home/door",    // GPIO 23 - Front Door Servo
    "home/buzzer"   // GPIO 5  - Doorbell Buzzer     <-- NEW
]
```

### Step 12 — Swift: add the toggle function

Under `// MARK: - Device Controls`, copy `toggleLight()`:

```swift
func toggleBuzzer() {
    let newState = !deviceStates.buzzerOn
    deviceStates.buzzerOn = newState
    receivedMessages.append("DEBUG: Buzzer toggled to \(newState ? "ON" : "OFF")")
    publishCommand(topic: "home/buzzer", command: newState ? "ON" : "OFF", device: "Doorbell Buzzer")
}
```

### Step 13 — Swift: handle send failures

Still in `MQTTClient.swift`, inside `publishCommand()`, there is a block that
undoes the toggle if the message could not be sent. Add your device:

```swift
if topic == "home/light" { self?.deviceStates.lightOn.toggle() }
else if topic == "home/garage" { self?.deviceStates.garageOpen.toggle() }
else if topic == "home/door" { self?.deviceStates.doorOpen.toggle() }
else if topic == "home/buzzer" { self?.deviceStates.buzzerOn.toggle() }   // <-- NEW
```

Skip this and the button will lie to you: it will look on while the buzzer is
off.

### Step 14 — Swift: add the card

In `DeviceControlsSection.swift`, inside the `LazyVGrid`:

```swift
DeviceCard(
    icon: "bell.fill",
    title: "Doorbell",
    subtitle: "Buzzer",
    isOn: mqttClient.deviceStates.buzzerOn,
    accentColor: .red,
    action: { mqttClient.toggleBuzzer() }
)
```

`icon` is an SF Symbol name. Browse them in the SF Symbols app, or try
`bell.fill`, `fan.fill`, `drop.fill`, `flame.fill`, `speaker.wave.2.fill`.

### Step 15 — Swift: fix the counter

The badge is hardcoded to three devices. In the same file:

```swift
Text("\(activeDevicesCount)/4 Active")     // was /3
```

and in `activeDevicesCount` below:

```swift
if mqttClient.deviceStates.buzzerOn { count += 1 }    // <-- NEW
```

---

## Checklist

Copy this for each new device you add.

**Raspberry Pi — `mqttlistener.py`**
- [ ] Pin constant in Section 1
- [ ] `TOPIC_` constant in Section 1
- [ ] Key in `device_states` (must match the last word of the topic)
- [ ] `GPIO.setup()` in `setup_gpio()`
- [ ] Topic added to the subscribe list in `on_connect()`
- [ ] `control_yourdevice()` function in Section 5
- [ ] `elif` branch in `on_message()`
- [ ] Tested with `mosquitto_pub`

**iPad app**
- [ ] `@Published` property in `Models.swift`
- [ ] Topic in the `topics` list in `MQTTClient.swift`
- [ ] `toggleYourDevice()` function
- [ ] Revert line in `publishCommand()`
- [ ] `DeviceCard` in `DeviceControlsSection.swift`
- [ ] Badge count and `activeDevicesCount` updated

---

## Harder extensions

**A device with a range, not just on/off.** A brightness-controlled LED or a
third servo needs a number, not `ON`/`OFF`. Send the number as the payload
(`mosquitto_pub -t home/lamp -m "75"`) and parse it:

```python
elif topic == TOPIC_LAMP:
    try:
        level = int(payload)
    except ValueError:
        publish_error(topic, f"Invalid level: {payload}. Use 0-100.")
        return
    if not 0 <= level <= 100:
        publish_error(topic, "Level must be 0-100.")
        return
    success = control_lamp(level)
```

In the app, a `Slider` replaces the button. You will need your own card rather
than `DeviceCard`, which only understands on/off — copy `GarageDoorCard.swift`,
which is already a custom card, as your starting point.

**A sensor instead of an output.** A PIR motion sensor or button reads *into*
the Pi (`GPIO.setup(PIN, GPIO.IN)`), then publishes a message rather than
receiving one. Look at `publish_device_status()` in Section 6 for how to send
data up to the app, and set the card's `action` to do nothing.

**Ideas worth trying:** porch light on a second LED, a fan using a transistor,
an RGB LED using three PWM pins, a reed switch that detects when the front door
is actually shut, a temperature sensor on the roof.

---

## Motors — DC and stepper

Motors are the one extension that needs more than a wire and a resistor. They
are worth doing, but read this section before buying parts.

The garage door used a 28BYJ-48 stepper in an earlier version of this project
and was changed to a servo, because a servo needs one pin, no driver board and
no separate power supply. If you want a motor back, you are re-adding that
complexity deliberately — which is a genuinely good extension exercise.

### Why a motor cannot go straight on a GPIO pin

| Component | Rough current |
|---|---|
| LED | 10 mA |
| SG90 servo, moving | 100–250 mA |
| 28BYJ-48 stepper | 200 mA+ |
| Small DC motor, stalled | 1 A or more |

A GPIO pin can supply about **16 mA**, and the whole chip about **50 mA**.
Connecting a motor directly will not work, and can damage the Pi. Every motor
needs two extra things:

1. **Its own power supply** — with the ground connected to a Pi GND pin, so
   the two share a common ground. Without the common ground the Pi and the
   driver disagree about what 0V means, and nothing works.
2. **A driver** — a transistor, Darlington array or H-bridge that lets a tiny
   GPIO signal switch a much larger current.

### Option A — DC motor

Simplest movement, but no position control: it spins while powered and coasts
to a stop.

- **One direction, on/off:** a single transistor (a 2N2222 for a very small
  motor, or a logic-level MOSFET) plus a **flyback diode** across the motor
  terminals. The diode is not optional — a motor coil generates a reverse
  voltage spike when switched off, which will eventually kill the transistor.
- **Both directions:** an H-bridge board such as an L298N, DRV8833 or
  TB6612FNG. Two GPIO pins select direction, a third does speed via PWM.

Speed control reuses the same PWM idea as the servos, but the number means
power rather than position:

```python
FAN_PIN = 12
fan_pwm = GPIO.PWM(FAN_PIN, 1000)   # 1 kHz suits a motor; 50 Hz would judder
fan_pwm.start(0)

def control_fan(speed: int) -> bool:
    """speed is 0-100 percent."""
    try:
        fan_pwm.ChangeDutyCycle(speed)
        logger.info(f"Fan -> {speed}%")
        return True
    except Exception as e:
        logger.error(f"Fan control error: {e}")
        return False
```

Send it a number rather than `ON`/`OFF`, and parse the payload the way the
range example above does.

### Option B — Stepper motor

Precise positioning without feedback: you tell it how many steps to move and
it moves exactly that far, as long as nothing stops it. This is *open-loop*
control — if the door jams, the Pi has no idea.

A 28BYJ-48 with a ULN2003 driver board is the usual classroom choice. It needs
**four GPIO pins**, one per coil, because the Pi energises the coils itself.

A ready-made test script is in the repo:

```bash
sudo systemctl stop simpsons-house.service
python3 extensions/stepper_test.py
```

It uses GPIO 5, 6, 13 and 19 and turns the motor one revolution each way. Read
the header comment first — it has the wiring and the power warning.

To drive it from MQTT, wrap the stepping logic in a control function and call
it from an `on_message()` branch, exactly like the eight steps above. Keep the
move short: `on_message()` is blocking, so a long slow rotation will freeze the
listener and delay every other command until it finishes.

### Pins to avoid

Already used by the standard build: **17** (light), **23** (front door servo),
**27** (garage servo).

Free to use: **5, 6, 12, 13, 16, 19, 20, 21, 26**.

---

## When it does not work

| Symptom | Check |
|---|---|
| Nothing happens, no log line | Topic missing from the subscribe list in `on_connect()` (Step 6) |
| Log says "unknown topic" | Topic spelled differently in Python and Swift — they must match exactly, and MQTT is case sensitive |
| Log says "Invalid command" | The app is sending a word your `valid_commands` dictionary does not contain |
| Works with `mosquitto_pub`, not from the app | Swift side — check Steps 11–14 |
| Button flips back by itself | Missing revert line (Step 13), or the Pi returned an error |
| Button stays on but nothing moves | Wiring or pin number, not code. Test the pin with `gpio_test.py` |
| Another device stopped working | Pin clash — two devices on the same GPIO number |
| Buzzer silent but pin is HIGH | Passive buzzer needs PWM, not a plain HIGH |

**Always work in this order:** wire it, test the pin, test with `mosquitto_pub`,
then add the app. Each stage rules out one whole layer.

---

## See also

- `WIRING_GUIDE.md` — identifying components and breadboard layout
- `SERVO_TUNING_GUIDE.md` — adjusting angles, direction and speed
- `TEACHING_GUIDE.md` — how the message travels from the iPad to the Pi
- `gpio_test.py` — hardware test for the pins already in the project

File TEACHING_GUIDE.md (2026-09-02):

# Teaching Guide — Simpson's House Smart Home

This guide is for teachers and students. It explains what every part of the project does, how the pieces connect, and what to look at when you want to change something.

---

## Quick mental model

Before diving into files, read this once:

```
You tap a button on the iPad
        ↓
The iPad app creates a tiny MQTT message ("ON")
        ↓
The message travels over WiFi to the Raspberry Pi
        ↓
The Mosquitto broker (a small program on the Pi) receives it
        ↓
mqttlistener.py (our Python script) receives it from the broker
        ↓
The Python script sends a HIGH/LOW signal to a GPIO pin
        ↓
The GPIO pin sends electricity to the real hardware
        ↓
The LED turns on / the servo moves
        ↓
The Python script publishes a status message back ("ON")
        ↓
The iPad app receives it and updates the button on screen
```

That whole loop takes less than a second.

---

## Part 1 — The Frontend (iPad App)

The iOS app is written in **SwiftUI** and lives in `SimpsonsHouse.swiftpm.zip`. Unzip it to see all the files. Here is what each one does.

### `MyApp.swift` — App entry point

This is the first file Swift runs when the app starts. It just tells SwiftUI "use `ContentView` as the starting screen." You almost never need to change this.

```swift
@main
struct MyApp: App {
    var body: some Scene {
        WindowGroup { ContentView() }
    }
}
```

**Teaching point:** The `@main` attribute marks the starting point of the whole program.

---

### `Models.swift` — Data that the UI watches

This file defines the data structures the app tracks. The key one is `DeviceStates`:

```swift
class DeviceStates: ObservableObject {
    @Published var lightOn    = false
    @Published var garageOpen = false
    @Published var doorOpen   = false
}
```

**Teaching point:** `@Published` is SwiftUI's magic word. When a `@Published` value changes, every view that uses it automatically redraws. It is how the button on screen changes from "ON" to "OFF" the moment the Pi replies.

---

### `MQTTClient.swift` — The networking engine

This is the most complex file. Students generally do NOT need to change it, but understanding it is valuable. It does three jobs:

**Job 1 — Connect to the Pi over WebSocket**

```swift
func connect() {
    let wsURL = URL(string: "ws://192.168.5.123:9001")
    webSocketTask = urlSession?.webSocketTask(with: request)
    webSocketTask?.resume()
}
```

WebSocket is a way of keeping a persistent two-way connection open. Port 9001 is where Mosquitto listens for WebSocket connections (as opposed to port 1883, which is raw TCP MQTT).

**Job 2 — Send MQTT packets manually**

MQTT has its own binary message format. The app builds these byte-by-byte:

```swift
private func createMQTTPublishPacket(topic: String, message: String) -> Data {
    var packet = Data()
    packet.append(0x30)   // ← first byte: "this is a PUBLISH packet"
    // ... more bytes follow (topic name, message, lengths)
}
```

Teaching point: Network protocols are just agreed formats for bytes. The Pi's Mosquitto broker expects bytes in this exact order — the code is doing exactly what the MQTT specification says.

**Job 3 — Call the right function when a reply arrives**

```swift
private func handleMQTTData(_ data: Data) {
    let messageType = (data[0] >> 4) & 0x0F
    switch messageType {
    case 2:  // CONNACK — broker confirmed our connection
    case 3:  // PUBLISH — a status update from the Pi
    case 13: // PINGRESP — Pi replied to our keep-alive ping
    }
}
```

Teaching point: `>>` is a bit-shift. The first byte of every MQTT packet encodes the message type in its top 4 bits. Shifting right by 4 extracts those bits.

---

### `ContentView.swift` — The screen layout

This is the root view — the "frame" that holds everything else together. Students can safely read and modify this file.

```swift
VStack(spacing: 24) {
    HeroSectionView()            // Title banner at the top
    ConnectionStatusCard(...)    // Shows Connected/Disconnected
    if mqttClient.isConnected {
        DeviceControlsSection(...)  // Buttons for each device
    } else {
        ConnectionPromptView()      // "Tap to Connect" message
    }
}
```

**Teaching point:** The `if mqttClient.isConnected` block is reactive — when `isConnected` changes (because the Pi replied), SwiftUI automatically swaps between showing the controls or the prompt. You did not have to write any "show this, hide that" code.

**Where students can experiment:**
- Change `spacing: 24` to see the sections move closer/further apart
- Add `HeroSectionView()` twice to see it appear twice (then remove the duplicate)
- Change `.background(Color(.systemBackground))` to `.background(Color.yellow.opacity(0.1))` for a yellow tint

---

### `HeroSectionView.swift` — Title banner

The decorative header at the top of the screen. It is completely safe to customise.

**Where students can experiment:**
- Change the title text or emoji
- Change the subtitle text
- Adjust colours and font sizes

---

### `ConnectionStatusCard.swift` — Connection indicator

Shows whether the app is talking to the Pi. Displays the status string from `mqttClient.connectionStatus` and has buttons to open the Logs and Info sheets.

**Teaching point:** Notice it takes `mqttClient` as a parameter. This means it does not own the data — `ContentView` owns it and shares it downward. This is called "dependency injection."

---

### `ConnectionPromptView.swift` — Offline state

A simple view shown when not connected. Has one button:

```swift
Button("Connect to House") {
    mqttClient.connect()
}
```

**Teaching point:** The button calls a function on the MQTT client. Students often ask "but how does it know what mqttClient is?" — it comes in through a `@Binding` or as an `ObservableObject` passed from the parent view.

---

### `DeviceControlsSection.swift` — The grid of device tiles

Arranges the three device cards in a layout:

```swift
LazyVGrid(columns: [...]) {
    DeviceCard(...)       // Living Room Light
    GarageDoorCard(...)   // Garage Door
    DeviceCard(...)       // Front Door
}
```

**Where students can experiment:**
- Add another `DeviceCard` row for a hypothetical new device
- Change the grid column count to make it 1 column or 3 columns

---

### `DeviceCard.swift` — Reusable device tile

A single on/off toggle card used for the light and the front door.

Key parts:
```swift
Button(action: { onToggle() }) {
    VStack {
        Image(systemName: icon)   // SF Symbol icon
        Text(title)
        Text(isOn ? "ON" : "OFF")
    }
}
.background(isOn ? Color.yellow : Color.gray)
```

**Teaching point:** `onToggle` is a **closure** (a function passed as a value). The card does not know what toggling means — the parent decides and passes the behaviour in. This makes the card reusable for any device.

---

### `GarageDoorCard.swift` — Garage-specific tile

Similar to `DeviceCard` but has separate OPEN and CLOSE buttons instead of a toggle, because OPEN and CLOSE are absolute positions, not a toggle — sending OPEN when the door is already open simply re-asserts that angle.

---

### `LogsView.swift` — Activity log sheet

Shows a scrollable list of everything that has happened: commands sent, replies received, errors. Very useful for debugging when the hardware is not responding.

---

### `InfoView.swift` — System info sheet

Shows the IP address, port, topic names, and other configuration. A handy reference without opening the code.

---

### `DebugConnectionView.swift` — Developer debugging tool

A panel used during development. Has a "Force Connection Fix" button that manually sets `isConnected = true` — useful when diagnosing connection state bugs. Not something students normally need.

---

## Part 2 — The Backend (Raspberry Pi Python)

All the backend code lives in `mqttlistener.py`. It is divided into numbered sections (see the comments in the file). Here is the plain-English summary.

### Section 1: Configuration

All the settings — which GPIO pins are used, the MQTT broker address, the topic names — are defined at the top as constants. This means students only need to change one place if the hardware is rewired.

```python
LIGHT_PIN        = 17
GARAGE_SERVO_PIN = 27
SERVO_PIN        = 23
BROKER_HOST      = "localhost"
BROKER_PORT      = 1883
```

---

### Section 2: Logging

Uses Python's `logging` library instead of `print()` so every message gets a timestamp and severity level:

```
2026-04-17 09:12:03 [INFO] Simpson's House: 💡 Living Room Light → ON
```

This makes it much easier to read the terminal output and understand the timeline of events.

---

### Section 3: GPIO Setup (`setup_gpio`)

Runs once at startup. Tells the Raspberry Pi:
- Which numbering scheme to use (BCM — matches the numbers on the pinout diagram)
- Which pins are outputs (driving components) vs inputs (reading sensors)
- Initial states (everything starts OFF)
- Sets up 50 Hz PWM on both servo pins

---

### Section 4: Servo Control (`set_servo_angle`)

Both doors are driven by **SG90 hobby servos** — the garage door on GPIO 27, the
front door on GPIO 23. Neither needs a driver board.

**Why no driver board?**
A servo has its own motor, gearbox and control circuit inside. The Pi only sends
it a low-current *signal*; the servo does the work. The 5V pin supplies enough
current for an SG90 directly.

**How the servo knows where to go:**
The Pi sends a 50 Hz pulse train. The *width* of each pulse tells the servo the
angle. The servo compares that against its internal position sensor and drives
its motor until they match, then holds.

```python
duty = (angle / 180.0) * 10 + 2   # 0° → 2%, 180° → 12%
pwm.ChangeDutyCycle(duty)
time.sleep(0.8)                    # give the servo time to travel
pwm.ChangeDutyCycle(0)             # stop pulsing so it doesn't hum
```

One function serves both doors — you pass in the PWM object for whichever servo
you want to move. `control_garage_door()` and `control_door()` both map
**open = 90°, closed = 0°**. Change those angles to match how you physically
mount the servo horn.

**Teaching point:** this is the difference between *open-loop* and *closed-loop*
control. A stepper is open-loop — you count steps and hope. A servo is closed-loop
— it measures its own position and corrects itself. (Driving a stepper is a
student extension: see `EXTENSION_GUIDE.md`.)

---

### Section 5: MQTT Event Handlers

Three functions the MQTT library calls automatically:

| Function | When it's called | What it does |
|---|---|---|
| `on_connect` | When connected to Mosquitto | Subscribes to all three topics, publishes initial device states |
| `on_disconnect` | When connection drops | Logs the event |
| `on_message` | When a message arrives | Decodes it, validates it, calls the device function, publishes status back |

`on_message` is the most important. The decision flow is:

```
Message arrives on "home/light"
    → Is it "ON" or "OFF"?
        → Yes → call control_light(True/False)
        → No  → publish error, ignore message
```

---

### Section 6: Device Control Functions

| Function | Hardware it controls | How |
|---|---|---|
| `control_light(state)` | LED on GPIO 17 | Sets pin HIGH or LOW |
| `control_garage_door(open_door)` | Servo motor on GPIO 27 | Calls `set_servo_angle(GARAGE_SERVO_PWM, 90 or 0)` |
| `control_door(state)` | Servo motor on GPIO 23 | Calls `set_servo_angle(SERVO_PWM, 90 or 0)` |

Both call the same `set_servo_angle()` helper — only the PWM object differs.

---

### Section 7: Shutdown

- `cleanup_and_exit()` — stops both PWM channels and releases the GPIO pins
- Runs from the `finally` block in `main()`, so it executes even on a crash
- The MQTT "last will" message also tells the app the controller went offline

---

### Section 8: MQTT Publishing

After carrying out a command, the Pi sends a status update back to the app:

| Topic | What it contains | Example value |
|---|---|---|
| `home/light/status` | Plain text | `ON` |
| `home/garage/status` | Plain text | `OPEN` |
| `home/door/status` | Plain text | `ON` |
| `home/status` | JSON | All device states + timestamp |
| `home/system` | JSON | Version, GPIO pin layout |

`retain=True` means Mosquitto remembers the last message. When the app reconnects it immediately gets the current state.

---

### Section 9–11: Utilities, Shutdown, and Main

- **Signal handling** — catches Ctrl+C (`SIGINT`) and `systemd stop` (`SIGTERM`) to shut down cleanly
- **`cleanup_and_exit`** — stops both PWM channels, turns off LEDs, releases GPIO, disconnects from MQTT
- **`main`** — the entry point: initialises GPIO, creates the MQTT client, connects, then runs forever processing messages

---

## Part 3 — The Infrastructure (Mosquitto Broker)

Mosquitto is a small program that runs on the Pi in the background. Students don't write code for it, but understanding its role is important.

**What it does:** Receives messages from publishers, routes them to subscribers on the same topic.

```
iPad publishes → home/light → "ON"
                      ↓
              Mosquitto broker
                      ↓
mqttlistener.py subscribed to home/light receives "ON"
```

**Two ports:**
- **1883** — raw MQTT (used by command-line tools like `mosquitto_pub`)
- **9001** — MQTT over WebSocket (used by the iPad app)

**Useful commands to run on the Pi:**

```bash
# Watch all messages in real time
mosquitto_sub -h localhost -t home/# -v

# Manually send a command (useful for testing without the iPad)
mosquitto_pub -h localhost -t home/light -m ON
mosquitto_pub -h localhost -t home/garage -m OPEN
mosquitto_pub -h localhost -t home/door -m ON

# Check the broker is running
sudo systemctl status mosquitto
```

---

## Part 4 — Step-by-step: what happens when you tap "Light ON"

1. **DeviceCard.swift** — `onToggle()` closure is called
2. **MQTTClient.swift** `toggleLight()` — flips `deviceStates.lightOn` to `true`, calls `publishCommand(topic: "home/light", command: "ON")`
3. **MQTTClient.swift** `publishCommand` — calls `createMQTTPublishPacket("home/light", "ON")` to build a 13-byte binary MQTT packet
4. **MQTTClient.swift** — sends the packet over the WebSocket to `ws://192.168.5.123:9001`
5. **Mosquitto** (on Pi) — receives the WebSocket data, unwraps it as an MQTT PUBLISH packet, routes it to all subscribers of `home/light`
6. **mqttlistener.py** `on_message()` — receives the message, decodes payload: `b'ON'` → `"ON"`
7. **mqttlistener.py** `control_light(True)` — runs `GPIO.output(17, GPIO.HIGH)` → 3.3V on pin 17
8. **GPIO 17** → current flows through 220Ω resistor → **LED lights up**
9. **mqttlistener.py** `publish_device_status("light", True)` — publishes `"ON"` to `home/light/status`
10. **Mosquitto** routes the status message back to the app's WebSocket
11. **MQTTClient.swift** `handleMQTTData()` — receives it, logs `"📨 House status update received"`
12. The `@Published var deviceStates` change triggers SwiftUI to redraw the `DeviceCard` → button now shows yellow "ON" state

---

## Part 5 — Student exercises

### Beginner: Customise the app appearance

Open `SimpsonsHouse.swiftpm` in Swift Playgrounds and find:

1. In `HeroSectionView.swift` — change the title emoji and text
2. In `ContentView.swift` — change the background colour
3. In `DeviceCard.swift` — change the "ON" colour from `Color.yellow` to `Color.green`

Run the app and see the changes immediately.

---

### Intermediate: Change how far the garage door opens

On the Raspberry Pi, open `mqttlistener.py`:

```python
GARAGE_TRAVEL_STEPS = 100   # ← change this number
```

Increase it (e.g. 200) and restart the service:

```bash
sudo systemctl restart simpsons-house
```

Send an OPEN command and observe whether the door travels further:

```bash
mosquitto_pub -h localhost -t home/garage -m OPEN
```

Adjust until the travel distance matches your physical model.

---

### Intermediate: Add terminal logging for the servo angle

In `control_door()` in `mqttlistener.py`, the servo angle is calculated as `90 if state else 0`. Change the fully-open angle to 120° and verify you can see the servo move further. Add a log message to print the exact duty cycle being sent.

---

### Advanced: Add a new device

**Step 1 — Backend:** In `mqttlistener.py`:

```python
# Add a new constant
FAN_PIN = 25

# In setup_gpio(), add:
GPIO.setup(FAN_PIN, GPIO.OUT, initial=GPIO.LOW)

# Add a new control function:
def control_fan(state: bool) -> bool:
    GPIO.output(FAN_PIN, GPIO.HIGH if state else GPIO.LOW)
    logger.info(f"🌀 Fan → {'ON' if state else 'OFF'}")
    return True

# In on_connect(), subscribe to the new topic:
client.subscribe("home/fan")

# In on_message(), add a new elif branch:
elif topic == "home/fan":
    valid_commands = {"ON": True, "OFF": False}
    command_state  = valid_commands.get(payload)
    success        = control_fan(command_state)
```

**Step 2 — Frontend:** In `DeviceControlsSection.swift`, add:

```swift
DeviceCard(
    title: "Fan",
    icon: "wind",
    isOn: mqttClient.deviceStates.fanOn,
    onToggle: { mqttClient.toggleFan() }
)
```

Then add `var fanOn = false` to `DeviceStates` in `Models.swift`, and add `toggleFan()` to `MQTTClient.swift` following the same pattern as `toggleLight()`.

---

### Advanced: Monitor all MQTT traffic live

On the Pi, run:

```bash
mosquitto_sub -h localhost -t home/# -v
```

Then use the iPad app to control devices. Observe every message published in both directions in real time. Try to match each line of terminal output to a step in the "Part 4" trace above.

---

## Part 6 — Common questions

**Q: Why does the app use WebSocket (port 9001) instead of direct MQTT (port 1883)?**

iOS does not have a built-in MQTT library. WebSocket is a standard protocol that iOS's `URLSession` supports natively. By telling Mosquitto to accept MQTT packets wrapped in WebSocket frames (on port 9001), we can talk MQTT from any iOS app without third-party libraries.

**Q: Why does each servo need only one GPIO pin?**

Everything the servo needs to know travels on a single signal wire, encoded as the width of a repeating pulse. The servo's own circuit reads that pulse and drives its motor. A stepper is the opposite — it needs four pins, because the Pi has to energise each coil itself. That is covered as an extension in `EXTENSION_GUIDE.md`.

**Q: Why not just use `GPIO.HIGH/LOW` for the servo too?**

Servos need a very precise timing signal (a pulse between 1ms and 2ms wide, repeated 50 times per second) to know their target angle. PWM (Pulse Width Modulation) generates exactly that. GPIO.HIGH/LOW is on/off — no timing information.

**Q: What happens if the Pi crashes while a servo is moving?**

The `cleanup_and_exit()` function runs in the `finally` block of `main()`, which Python always executes even on a crash. It stops both PWM channels and releases the GPIO pins before the process exits. The MQTT "last will" message also tells the app the controller went offline.

**Q: Why does `retain=True` matter on status topics?**

Without `retain=True`, if the app connects AFTER the last status was published, it would not know the current state of the devices — it would show everything as OFF even if the light is on. With retain, Mosquitto caches the last message and delivers it immediately to any new subscriber.

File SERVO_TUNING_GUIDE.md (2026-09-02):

# Servo Tuning Guide — Simpson's House

How to change how far the front door and garage door open, which way they
swing, and how fast they move.

Every model is cut and glued slightly differently, so the angles in the repo
are a starting point, not the right answer. Expect to tune them.

---

## The short version

If you just want to change how far a door opens, these five steps are the whole job.

**1. Stop the service** (it holds the GPIO pins):
```bash
sudo systemctl stop simpsons-house.service
```

**2. Find your angles** by jogging the servo:
```bash
python3 servo_calibrate.py
```
Type `g` for garage or `d` for front door, then type angles (`0`, `45`, `90`) and watch the door. Write down the number where it looks shut and the number where it looks open.

**3. Open `mqttlistener.py`** and find the line for your door:

| Door | Function | Find this line |
|---|---|---|
| Garage | `control_garage_door()` | `angle = 90 if open_door else 0` |
| Front door | `control_door()` | `angle = 90 if state else 0` |

**4. Put your two numbers in.** The first number is OPEN, the second is CLOSED. If your garage looked right at 60 open and 5 shut:

```python
# before
angle = 90 if open_door else 0
# after
angle = 60 if open_door else 5
```

**5. Start the service again** and test from the iPad:
```bash
sudo systemctl start simpsons-house.service
```

That is it. The rest of this guide explains why those numbers work, how to reverse a door that opens the wrong way, and how to slow the movement down.

---

## Before you start

**Stop the service first.** The background service holds the GPIO pins. If you
run a test script while it is running, both programs fight over the same servo
and you get twitching and confusing results:

```bash
sudo systemctl stop simpsons-house.service
```

Start it again when you have finished tuning:

```bash
sudo systemctl start simpsons-house.service
```

**Golden rules:**
- Change one number at a time, then test
- If a servo buzzes or gets warm, stop — it is straining, not working
- Never force a door by hand while the servo is powered

---

## How a servo hears an angle

A servo does not understand degrees. It listens for a pulse, repeated 50 times
a second, and moves to the position that pulse length represents.

```
   one cycle = 20 ms  (50 Hz)
   |<--------------------------------->|
    ____                                ____
   |    |______________________________|    |____
   |<-->|
   pulse length decides the position

   0.4 ms  ->    0 degrees
   1.4 ms  ->   90 degrees
   2.4 ms  ->  180 degrees
```

`mqttlistener.py` converts your angle into that pulse inside
`set_servo_angle()`:

```python
duty = (angle / 180.0) * 10 + 2
```

Duty cycle is the percentage of each cycle the pulse is switched on. So
**0 degrees = 2%**, **90 degrees = 7%**, **180 degrees = 12%**.

Two lines below it are easy to misread:

```python
time.sleep(0.8)          # wait for the servo to physically arrive
pwm.ChangeDutyCycle(0)   # stop pulsing so it does not hum
```

The `sleep` is a **wait**, not a speed setting. The servo always travels at
full speed. Making the sleep longer just adds a pause after it arrives.
See [Changing the speed](#changing-the-speed) for how to actually slow it down.

Cutting the signal afterwards means the servo stops holding its position. It
runs cooler and quieter, but the door can be nudged open by hand. That is
deliberate.

---

## The two lines you will edit

Both doors use the same helper. Only the angles differ.

| Door | Function in `mqttlistener.py` | The line |
|---|---|---|
| Garage | `control_garage_door()` | `angle = 90 if open_door else 0` |
| Front door | `control_door()` | `angle = 90 if state else 0` |

Read it as: **open = 90 degrees, closed = 0 degrees.**

Pins, for reference (BCM numbering, set near the top of the file):

| Door | GPIO | Physical pin |
|---|---|---|
| Garage servo | 27 | 13 |
| Front door servo | 23 | 16 |

---

## Finding your angles

Rather than guessing and restarting the service each time, jog the servo live.

```bash
sudo systemctl stop simpsons-house.service
python3 servo_calibrate.py
```

At the prompt:

| Type this | What happens |
|---|---|
| `g` | switch to the garage servo |
| `d` | switch to the front door servo |
| `90` | move to 90 degrees |
| `s 0 90 2.5` | sweep 0 to 90 degrees over 2.5 seconds |
| `hold` | keep the servo powered so it resists being moved |
| `release` | stop pulsing after each move (the default) |
| `q` | quit and clean up the pins |

It prints the duty cycle and pulse width next to every move, which makes the
maths above concrete for students.

**Method:**
1. Type `0` and look at the door. Is it properly shut?
2. Work upwards — `20`, `40`, `60` — until it looks properly open.
3. Note those two numbers. They are your closed and open angles.
4. Put them into the two lines above.
5. Restart the service and test from the iPad.

---

## Setting the travel

If the garage door looks fully open at 60 degrees, edit `control_garage_door()`:

```python
angle = 60 if open_door else 0
```

Closed does not have to be 0 either. If the door is slightly ajar at 0, try:

```python
angle = 60 if open_door else 8
```

---

## Reversing the direction

If a servo opens the door the wrong way, swap the two numbers instead of
remounting the servo:

```python
angle = 0 if open_door else 90
```

---

## Changing the speed

A default move snaps the door open — an SG90 covers about 60 degrees in a tenth
of a second. To make it swing, step through the positions in between.

Add this function to `mqttlistener.py`, next to `set_servo_angle()`:

```python
def sweep_servo_angle(pwm, start, end, label="Servo", seconds=1.5, steps=50):
    """Move gradually from start to end so the door swings instead of snapping."""
    try:
        for i in range(steps + 1):
            angle = start + (end - start) * (i / steps)
            pwm.ChangeDutyCycle((angle / 180.0) * 10 + 2)
            time.sleep(seconds / steps)
        pwm.ChangeDutyCycle(0)
        logger.info(f"{label} swept {start} -> {end} degrees over {seconds}s")
        return True
    except Exception as e:
        logger.error(f"Servo sweep failed ({label}): {e}")
        return False
```

Then call it from `control_garage_door()`:

```python
start, end = (0, 90) if open_door else (90, 0)
success = sweep_servo_angle(GARAGE_SERVO_PWM, start, end,
                            label="Garage Door Servo", seconds=2.0)
```

- Larger `seconds` — slower
- More `steps` — smoother; below about 20 the movement looks steppy

Try `s 0 90 2.5` in the calibration script first to pick a speed you like.

> **Watch the power.** A slow sweep draws current for longer. If the Pi resets
> when both doors move together, stagger them or move to an external 5V supply.

---

## Do not forget the log messages

Just below each angle line, the log text has the old value written into it:

```python
logger.info(f"Garage Door -> {'OPEN (90°)' if open_door else 'CLOSED (0°)'}")
```

If you change the angle to 60, update this too, or your logs will lie to you
during troubleshooting.

---

## Troubleshooting

| Symptom | Likely cause | Fix |
|---|---|---|
| Buzzing, servo warm | Angle is past the mechanical stop | Back off 10–15 degrees. Most SG90s only reach about 170, not 180 |
| Constant small twitching | Software PWM jitter | Normal. The code already drops to `ChangeDutyCycle(0)` after each move |
| Pi reboots when a door moves | Both servos browning out the 5V rail | Stagger the doors, or use an external 5V supply with common ground |
| Door moves the wrong way | Servo mounted mirrored | Swap the two angle numbers |
| Door creeps open by itself | Signal released, servo not holding | Expected. Use `hold` behaviour only if you really need it |
| Nothing moves at all | Service still running and holding the pins | `sudo systemctl stop simpsons-house.service` first |
| Moves in the test script, not from the iPad | Service not restarted after editing | `sudo systemctl restart simpsons-house.service` |

---

## Quick reference

```
Stop service      sudo systemctl stop simpsons-house.service
Calibrate         python3 servo_calibrate.py
Edit angles       mqttlistener.py -> control_garage_door() / control_door()
Restart service   sudo systemctl restart simpsons-house.service
Watch the logs    journalctl -u simpsons-house.service -f
```

| Angle | Duty | Pulse |
|---|---|---|
| 0° | 2% | 0.4 ms |
| 45° | 4.5% | 0.9 ms |
| 90° | 7% | 1.4 ms |
| 135° | 9.5% | 1.9 ms |
| 180° | 12% | 2.4 ms |

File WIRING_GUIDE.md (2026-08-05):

# Wiring Guide — Simpson's House

Work through each section in order. Wire one device, test it, then move on.
Never wire everything at once — it makes faults much harder to find.

---

## Before you start

**Run this command on the Pi first:**
```bash
pinout
```
It prints a colour-coded diagram of the physical board. Keep it open in a second terminal window while you wire. Every pin number in this guide refers to the **GPIO (BCM) number**, not the physical pin position.

**Golden rules:**
- Always power the Pi OFF before adding or removing wires
- One wire at a time — plug in, check, then plug in the next
- If something smells hot, power off immediately

---

## Device 1 — Living Room Light (LED)

### Identifying the LED

An LED has two legs. They are NOT the same:

```
     ___
    /   \
   | LED |
    \___/
      |  \
      |   \
   LONG   SHORT
   leg    leg
    (+)   (-)
  Anode  Cathode
```

- **Longer leg = Anode = positive (+)** — this connects toward the GPIO pin
- **Shorter leg = Cathode = negative (−)** — this connects toward GND
- The plastic body also has a **flat edge** on one side — the flat edge is always the cathode (−) side

> If you put the LED in backwards it simply will not light. It will not break,
> just swap the legs around.

### Identifying the resistor

A 220Ω resistor has colour bands: **Red – Red – Brown – Gold**.

```
   __|__
  |     |     Red  = 2
  | 220 |     Red  = 2
  |_____|     Brown = × 10
    | |       Gold  = ± 5%
              → 22 × 10 = 220Ω
```

Resistors have no polarity — either leg can go in either direction.

### Where to place it on the breadboard

The breadboard has two halves (top rows a–e, bottom rows f–j) connected across the middle gap. Columns are numbered. Power rails run along the long edges.

```
   Breadboard (top view)
   ┌────────────────────────────────────────┐
   │  + rail ································│  ← 5V (not used here)
   │  - rail ································│  ← GND rail
   │                                        │
   │  a b c d e   f g h i j                 │
   │  ─────────   ─────────                 │
   │  [col 1  ]   [      ]     row 1        │
   │  [col 2  ]   [      ]     row 2        │
   │  [col 3  ]   [      ]     row 3        │
   │  [col 4  ]   [      ]     row 4        │
   │  [col 5  ]   [      ]     row 5        │
   │                                        │
   │  + rail ································│  ← 5V (not used here)
   │  - rail ································│  ← GND rail
   └────────────────────────────────────────┘
```

**Place the LED across the centre gap:**
- Long leg (+) → column e, row 3 (left half)
- Short leg (−) → column f, row 3 (right half)

**Place the resistor in the left half:**
- One leg → column a, row 1
- Other leg → column a, row 3 (same row as the LED's long leg)

### Wire connections (step by step)

Make these connections ONE AT A TIME:

| Step | From | To | Wire colour suggestion |
|---|---|----|---|
| 1 | Pi GPIO 17 (physical pin 11) | Breadboard column a, row 1 | Yellow |
| 2 | Breadboard column a, row 1 | Resistor leg 1 | — (resistor bridges rows 1–3) |
| 3 | Resistor leg 2 | Column a, row 3 → LED anode (+, long leg) in column e, row 3 | — (resistor & LED in same half) |
| 4 | LED cathode (−, short leg) column f, row 3 | GND rail | Black |
| 5 | GND rail | Pi GND (physical pin 9) | Black |

### Circuit in plain English

```
Pi GPIO 17 → 220Ω resistor → LED (+) long leg → through LED → LED (−) short leg → GND → Pi GND
```

### Test it

```bash
python3 gpio_test.py
```

**Watch for:** the LED blinks 3 times (0.5 s on, 0.5 s off). If nothing happens, see Troubleshooting below.

### LED troubleshooting

| Symptom | Most likely cause | Fix |
|---|---|-----|
| LED doesn't light | LED in backwards | Swap the two legs |
| LED doesn't light | Wrong GPIO pin | Re-check pin 11 on `pinout` |
| LED doesn't light | Resistor not bridging rows | Check rows — resistor must connect column a row 1 to column a row 3 |
| LED is very dim | Resistor too high (wrong value) | Check colour bands: Red–Red–Brown–Gold |
| LED lights permanently, won't turn off | Short circuit somewhere | Power off, check no wires touching |

---

## Device 2 — Garage Door (Servo Motor)

The garage door uses the same kind of SG90 hobby servo as the front door, just on
a different GPIO pin. No driver board is needed — three wires straight to the Pi.

```
  ┌─────────────────┐  3 wires  ┌──────────────────┐
  │  Raspberry Pi   │──────────>│   SG90 Servo     │
  │  GPIO 27        │  signal   │   (garage door)  │
  │  5V, GND        │  power    │                  │
  └─────────────────┘           └──────────────────┘
```

A servo has a motor, gearbox and position sensor built in. You tell it *where* to
go as an angle, and it holds that position by itself — unlike a stepper, which has
to be driven coil by coil.

### Identifying the servo wires

Most SG90 hobby servos have three wires. The colours can vary between brands:

```
  Common wire colours for SG90 servos:
  ┌──────────┬──────────┬──────────┐
  │  Signal  │  Power   │  Ground  │
  │  (data)  │  (VCC)   │  (GND)   │
  ├──────────┼──────────┼──────────┤
  │  Orange  │  Red     │  Brown   │  ← most common
  │  Yellow  │  Red     │  Black   │  ← some brands
  │  White   │  Red     │  Black   │  ← some brands
  └──────────┴──────────┴──────────┘

  When in doubt: RED is always power (VCC, 5V)
```

### Wire connections (step by step)

| Step | Servo wire | Colour | From | To |
|---|---|---|---|----|
| 1 | Signal | Orange or Yellow or White | Servo signal wire | Pi GPIO 27 (physical pin 13) |
| 2 | Power | Red | Servo red wire | Pi 5V (physical pin 2) |
| 3 | Ground | Brown or Black | Servo brown/black wire | Pi GND (physical pin 14) |

> **Why 5V and not 3.3V?** The SG90 needs 5V to develop full torque. The signal
> wire is happy with the Pi's 3.3V logic — only the power wire must be 5V.

> **Note the pins are different from the front door.** Garage door is GPIO 27
> (pin 13); front door is GPIO 23 (pin 16). Swapping them makes the wrong door move.

### How the Pi controls the angle

```
Pi GPIO 27 ──> 50 Hz pulse train, pulse width 1ms–2ms
                        ↓
        servo's internal circuit compares pulse width to
        its position sensor and drives the motor until they match
                        ↓
              horn holds at the requested angle
```

In code this is a PWM duty cycle: 0° → 2%, 180° → 12%. The firmware uses
**0° = closed, 90° = open**, then sets the duty cycle to 0 so the servo stops
pulsing and doesn't hum while idle.

### Test it

```bash
python3 gpio_test.py
```

**Watch for:** the servo horn swings roughly a quarter turn, pauses, then swings
back. If it buzzes without moving, check the red wire is on 5V.

### Servo troubleshooting

| Symptom | Most likely cause | Fix |
|---|---|-----|
| Servo doesn't move at all | Signal wire on the wrong pin | Garage is GPIO 27 (pin 13), not GPIO 23 |
| Servo buzzes but barely moves | Powered from 3.3V instead of 5V | Move the red wire to a 5V pin |
| Servo doesn't move at all | Common GND missing | Check the brown/black wire to Pi GND |
| Servo hums continuously when idle | Still being sent pulses | The code should call `ChangeDutyCycle(0)` after each move |
| Servo moves the wrong way | Angles mapped the other way round | Swap the values in `control_garage_door()` |
| Servo won't reach full travel | SG90 unit variation, or door binding | Adjust the 2%–12% range in `set_servo_angle()`; check the door moves freely |
| Pi reboots when the servo moves | Both servos drawing peak current at once | Add an external 5V supply, GND common with the Pi |

---

## Device 3 — Front Door (Servo Motor)

### Identifying the servo wires

Most SG90 hobby servos have three wires. The colours can vary between brands:

```
  Common wire colours for SG90 servos:
  ┌──────────┬──────────┬──────────┐
  │  Signal  │  Power   │  Ground  │
  │  (data)  │  (VCC)   │  (GND)   │
  ├──────────┼──────────┼──────────┤
  │  Orange  │  Red     │  Brown   │  ← most common
  │  Yellow  │  Red     │  Black   │  ← some brands
  │  White   │  Red     │  Black   │  ← some brands
  └──────────┴──────────┴──────────┘

  When in doubt: RED is always power (VCC, 5V)
```

The three wires come out of the servo in a small 3-pin connector. The connector can be pushed directly onto male header pins or used with jumper wires.

### The servo connector orientation

```
  Servo 3-pin plug (looking at the pins head-on):
  ┌─────────────────────┐
  │   ○     ○     ○     │
  └─────────────────────┘
   Signal  VCC   GND
  (Orange) (Red) (Brown)

  Note: order may vary — always check the wire colours, not just position
```

### Wire connections (step by step)

| Step | Servo wire | Colour | From | To |
|---|---|---|---|----|
| 1 | Signal | Orange or Yellow or White | Servo signal wire | Pi GPIO 23 (physical pin 16) |
| 2 | Power | Red | Servo red wire | Pi 5V (physical pin 4) |
| 3 | Ground | Brown or Black | Servo brown/black wire | Pi GND (physical pin 6) |

> **Only three wires for the servo.** It does not need a driver board — the SG90
> draws little enough current that the Pi's 5V pin can power it directly.

### Circuit in plain English

```
Pi GPIO 23 → Servo SIGNAL wire  (orange/yellow/white)
Pi 5V      → Servo POWER wire   (red)
Pi GND     → Servo GROUND wire  (brown/black)

The servo contains its own motor + gearbox + position sensor.
Sending a PWM signal on the signal wire tells the servo what angle to go to.
```

### What 0° and 90° look like

When you run the test, the servo arm moves:
- **0°** — arm rotated fully to one end stop (the "closed door" position)
- **90°** — arm rotated 90° from that point (the "open door" position)

Exactly which physical direction that is depends on how you mount the servo. If it opens the wrong way, change the angles in `control_door()`:
```python
angle = 90 if state else 0   # change 90 to 180 if the arm moves the wrong way
```

### Test it

```bash
python3 gpio_test.py
```

**Watch for:** the servo arm sweeps from one position to 90°, holds for half a second, then returns to 0°.

### Servo troubleshooting

| Symptom | Most likely cause | Fix |
|---|---|-----|
| Servo doesn't move | Signal wire on wrong pin | Check orange/yellow wire → GPIO 23 (pin 16) |
| Servo twitches but doesn't hold position | Power wire not connected | Check red wire → 5V (pin 4) |
| Servo buzzes constantly | PWM not stopping after move | Check `SERVO_PWM.ChangeDutyCycle(0)` is called in `set_servo_angle()` |
| Servo moves to wrong position | Wrong duty cycle | Try changing the `angle` value in `control_door()` |
| Servo arm moves backwards | Mounted upside down | Physically flip the servo, or swap 0 and 90 in the code |

---

## Full wiring check — do this before first boot

Go through this checklist out loud with a partner. One person reads, one person points to each wire:

**LED:**
- [ ] Yellow wire: Pi GPIO 17 (pin 11) → resistor leg 1
- [ ] Resistor bridges to LED long leg (+) in same breadboard half
- [ ] LED short leg (−) → GND rail
- [ ] Black wire: GND rail → Pi GND (pin 9)

**Garage Door Servo:**
- [ ] Signal wire (orange/yellow/white): Servo → Pi GPIO 27 (pin 13)
- [ ] Power wire (red): Servo → Pi 5V (pin 2)
- [ ] Ground wire (brown/black): Servo → Pi GND (pin 14)

**Front Door Servo:**
- [ ] Signal wire (orange/yellow/white): Servo → Pi GPIO 23 (pin 16)
- [ ] Power wire (red): Servo → Pi 5V (pin 4)
- [ ] Ground wire (brown/black): Servo → Pi GND (pin 6)

**Run the test:**
```bash
python3 gpio_test.py
```

Expected output:
```
🏠 Simpson's House GPIO Test
──────────────────────────────
💡 TEST 1/3 — Living Room Light
   → Watch the LED: it should blink ON–OFF 3 times
✅ Light test passed

🚗 TEST 2/3 — Garage Door Servo (GPIO 27)
   → Watch the servo arm: it should move to 90° then return to 0°
✅ Garage door servo test PASSED

🚪 TEST 3/3 — Front Door Servo (GPIO 23)
   → Watch the servo arm: it should move to 90° then return to 0°
✅ Front door servo test PASSED

🏁 All tests passed — ready to run the full Simpson's House system!
```

If any test fails, see the troubleshooting table for that device above.

---

## Quick reference — GPIO pin map

The physical board has 40 pins. These are the ones we use:

```
  Physical   GPIO    Used for
  Pin        (BCM)
  ─────────────────────────────
  Pin  2     5V      Garage servo power  + (not a GPIO, just power)
  Pin  4     5V      Front door servo power + (not a GPIO, just power)
  Pin  6     GND     Front door servo GND  − (not a GPIO, just ground)
  Pin  9     GND     LED GND      − (not a GPIO, just ground)
  Pin 11     GPIO 17 LED (light)
  Pin 13     GPIO 27 Garage door servo signal
  Pin 14     GND     Garage servo GND    − (not a GPIO, just ground)
  Pin 16     GPIO 23 Front door servo signal
```

Run `pinout` on the Pi to see a colour-coded version of this on your screen.

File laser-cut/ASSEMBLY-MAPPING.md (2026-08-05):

# Proposed mapping: engraved part number → assembly-step callout

Engraved numbers are geometry IDs (`00`–`51`, assigned largest-first) shown in
`PART-CHART.pdf`. Callouts `01`–`55` are the step numbers in
`Simpsons_House_Assemble.pdf`.

The two sets do **not** line up one-to-one:

| | count |
|---|---|
| Distinct parts cut per house | 52 |
| Distinct *shapes* (after removing duplicates) | 40 |
| Assembly callouts | 55 |

The gap is because the instructions number each piece **as it is fitted**, so an
identical piece that goes in four times gets four callouts, and a few callouts
point at a sub-assembly rather than a new part.

Confidence is graded. Read the "why" column before trusting a row.

---

## Tier A — confident

Matched on a distinctive feature or on an exact dimension pair.

| Callout | Part | Why |
|---|---|---|
| 01 | **06** (173.1 × 90.1) | Feature-for-feature match in the p2 drawing: two rectangular window slots, two arched bay recesses, central arch notch. |
| 04, 05, 06, 07 | **22, 23, 24, 25** (23.3 × 42.0) | Four bay-window fins, two per bay. Exactly four callouts and exactly four geometrically identical parts — interchangeable, so any order works. |
| 13 | **51** (13.2 × 15.1) | The cross/plus-shaped key that slots into the gable wall. Only cruciform part in the set. |
| 22, 23 | **26, 27** (39.0 × 20.9) | The two upper-storey window frames. Identical pair, and the only 39 × 21 rectangular frames. |
| 44 | **00** (313.2 × 197.7) | The base plate — the driveway/path notch in the drawing matches part 00's outline exactly. Largest part in the set. |
| 53, 55 | **05** (86.8 × 183.4) and **07** (183.4 × 83.0) | The two main roof slopes. Both share the 183.36 mm ridge edge; nothing else in the set does. Which is which depends on ridge overlap — check the tab positions. |

## Tier B — probable

Shape and size fit, but I could not confirm every feature through the 3D views.

| Callout | Part | Why |
|---|---|---|
| 08 | **29** (22.1 × 35.7) | The arched interior door. Size and proportion fit; the drawing shows a knob hole I could not resolve on the flat part. |
| 09 | **34** (13.5 × 38.3) | The door linkage arm — has a pivot hole at one end and a hook at the other, matching the arm in p3. |
| 15, 16 | **17, 18** (24.4 × 87.1) | The two tall corner posts. Only near-identical tall strips in the set (areas 1105 / 1097 mm², so they are mirrored, not identical). |
| 24, 25, 27, 28 | **40, 41, 42, 43** (22.9 × 13.3) | Bay-window panes, two per bay. Four identical parts, four callouts. |
| 32 | **36** (24.4 × 20.1) | Chimney cap — a small rectangular ring, matching the chimney top in p5. |
| 12, 20 | **02** (124.4 × 157.7) and **04** (101.9 × 157.7) | The two gable end walls. Both share the 157.72 mm height; nothing else does. |

## Tier C — unresolved

I could not distinguish these reliably from the drawings. Sizes and likely roles
are given so you can settle them against physical parts in a minute or two.

| Parts | Likely role | Note |
|---|---|---|
| **37, 38** (15.0 × 25.9) | Bay-window side walls | Identical pair — order does not matter. |
| **47, 48, 49, 50** (14.7 × 14.6) | Bay-window roof triangles | Four identical parts. |
| **31, 32** (23.3 × 22.9) | Window inserts, 3 horizontal bars | Identical pair. |
| **09** (107.0 × 69.2), **10** (107.0 × 57.3) | Roof or garage panels | Share the 107.01 mm edge — a matched pair. |
| **12** (63.5 × 60.9), **13** (63.5 × 57.6) | Garage roof slopes | Share the 63.47 mm edge — a matched pair. |
| **15** (32.6 × 103.1) | Garage door | Slatted panel — distinctive, but its callout is not shown in the views I could read. |
| **01** (273.2 × 91.1), **03** (136.5 × 124.4) | Long front wall / internal partition | Both large and distinctive; I could not pin which callout. |
| **11** (103.1 × 57.0) | Bay floor + linkage mount | Carries a pivot hole; part of the door mechanism. |
| Remainder | Trim, brackets, steps | Small pieces, several near-identical. |

---

## The reliable way to finish this

Roughly half the set above is solid and half is not, and guessing the rest from
3D line drawings is not going to get more accurate.

Since the numbers are already engraved and `PART-CHART.pdf` shows every part:

1. Cut **one** house (sheets 1–11 produce 10, but one of each is enough to start).
2. Lay the parts on the chart to confirm the engraved IDs.
3. Walk the assembly PDF and write the callout beside each part.

That produces a verified table in about ten minutes. Send it back and the
engraving can be regenerated to carry the assembly numbers instead of the
geometry IDs — it is a one-line change to the label text in `nest.py`.

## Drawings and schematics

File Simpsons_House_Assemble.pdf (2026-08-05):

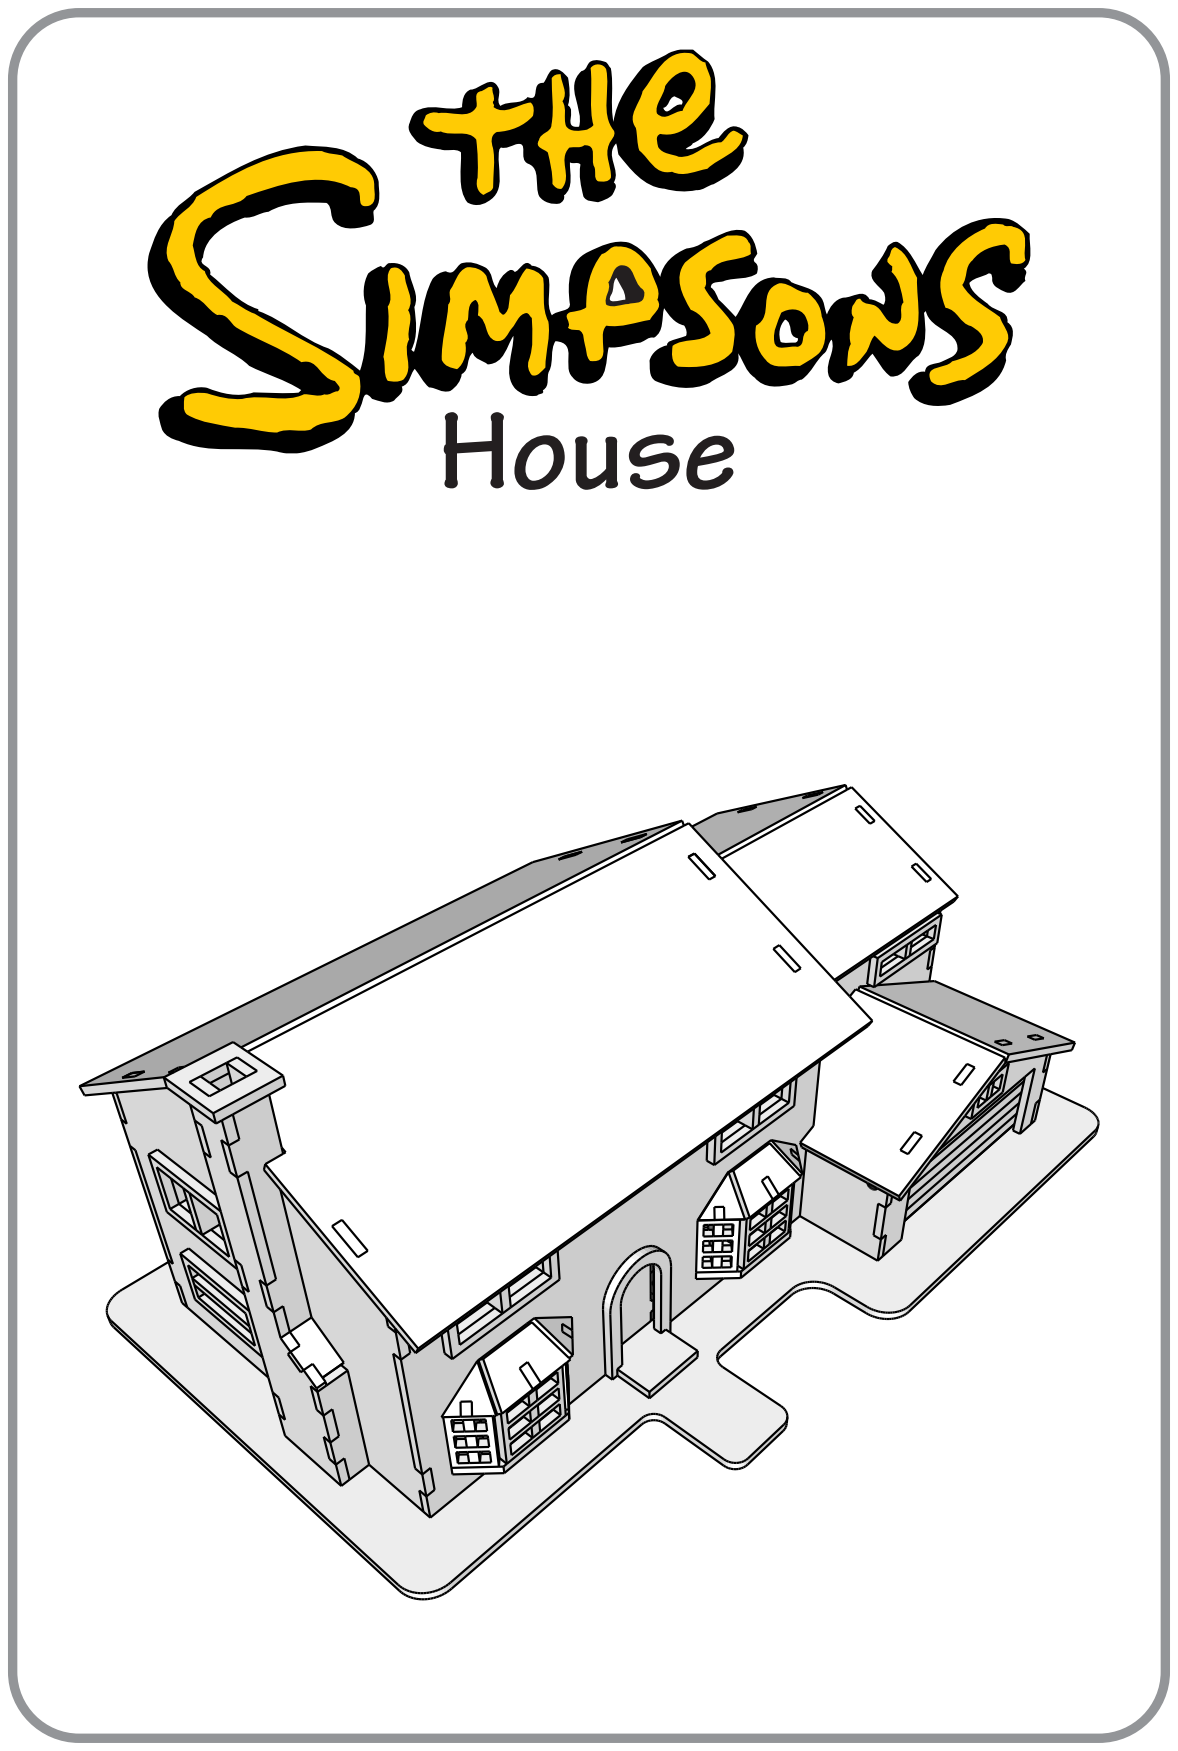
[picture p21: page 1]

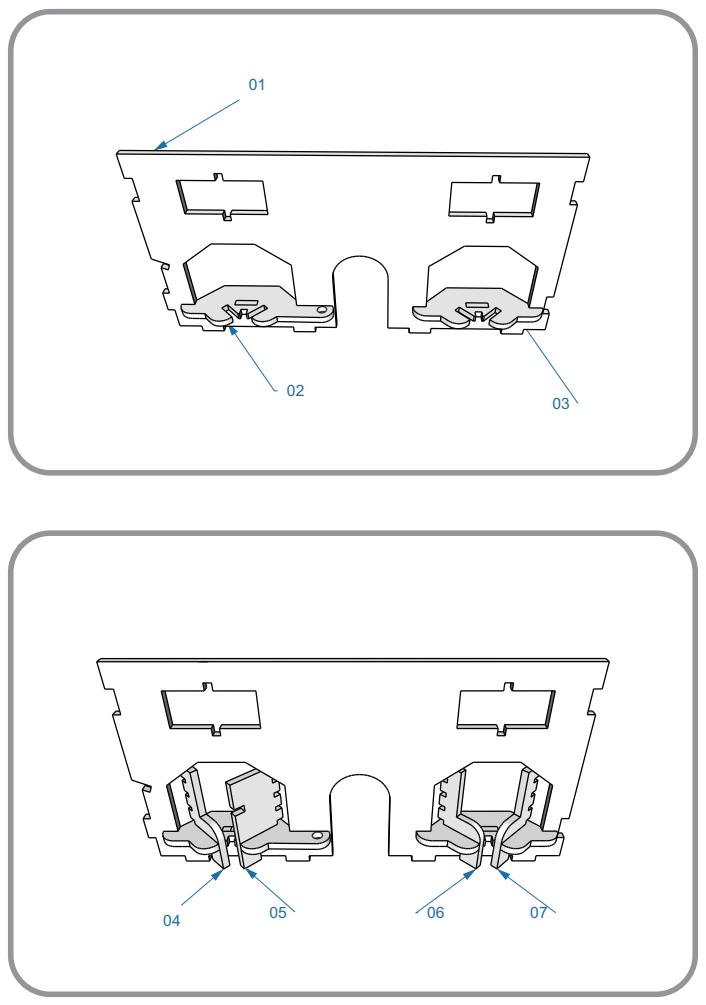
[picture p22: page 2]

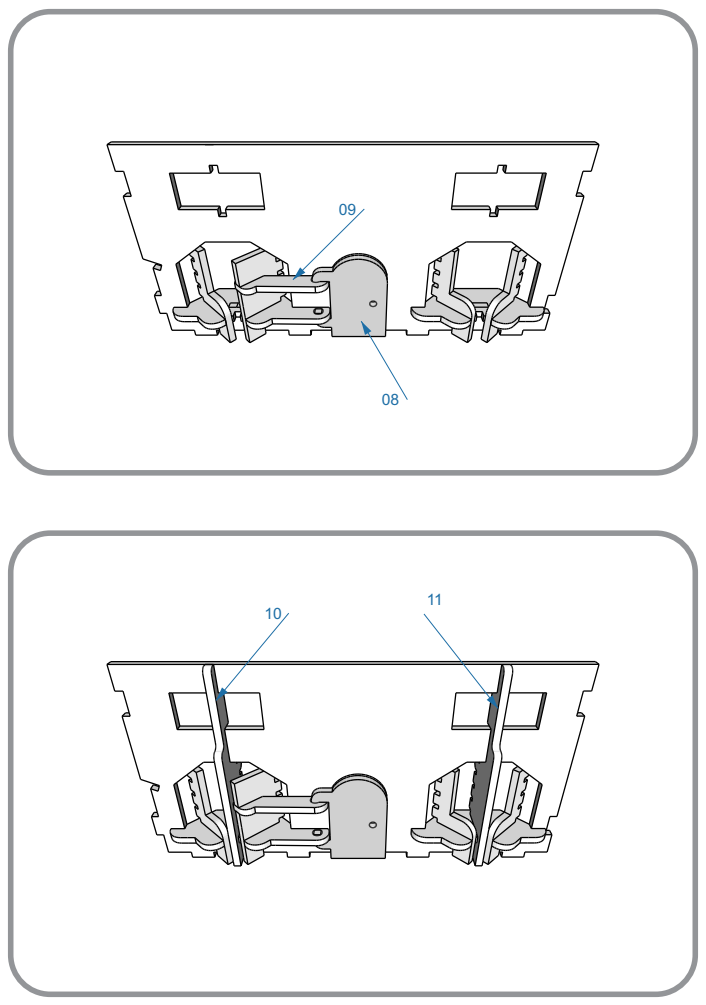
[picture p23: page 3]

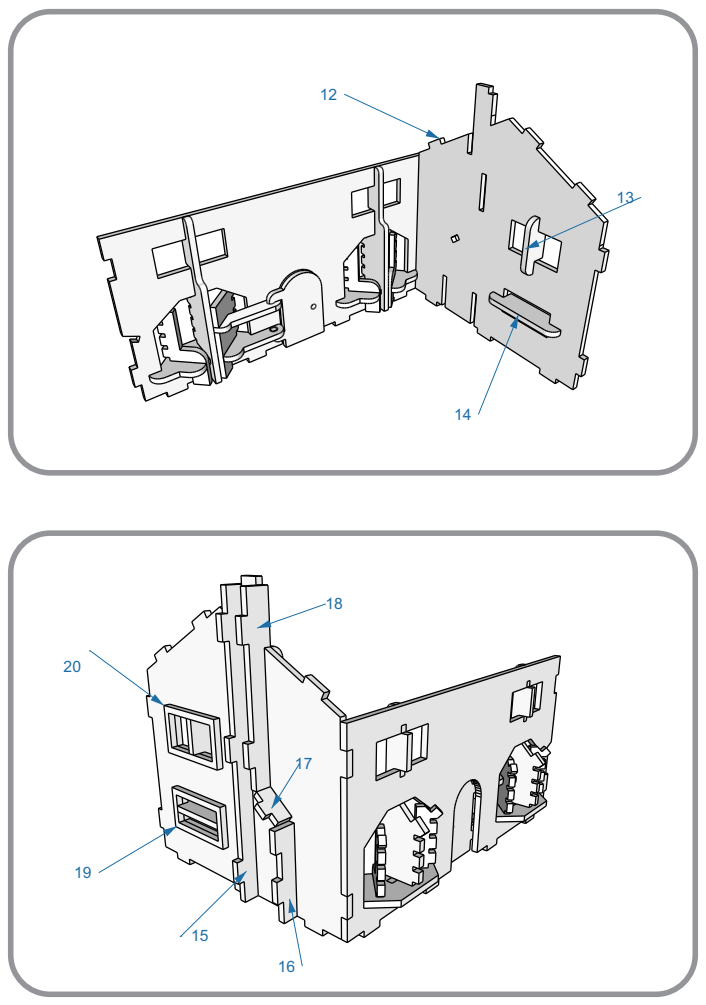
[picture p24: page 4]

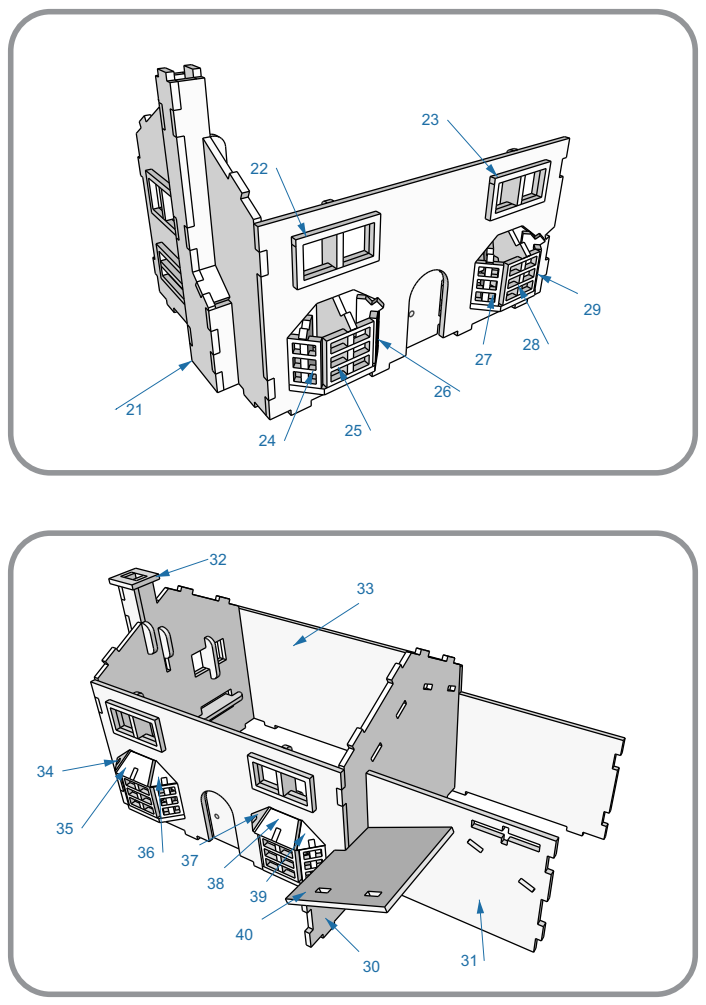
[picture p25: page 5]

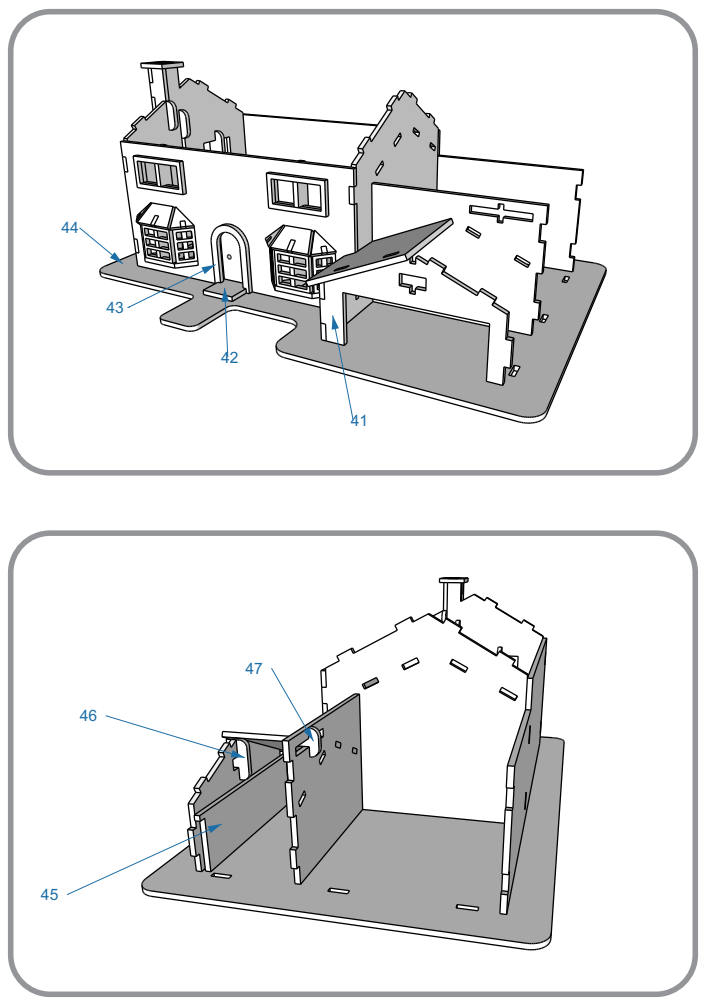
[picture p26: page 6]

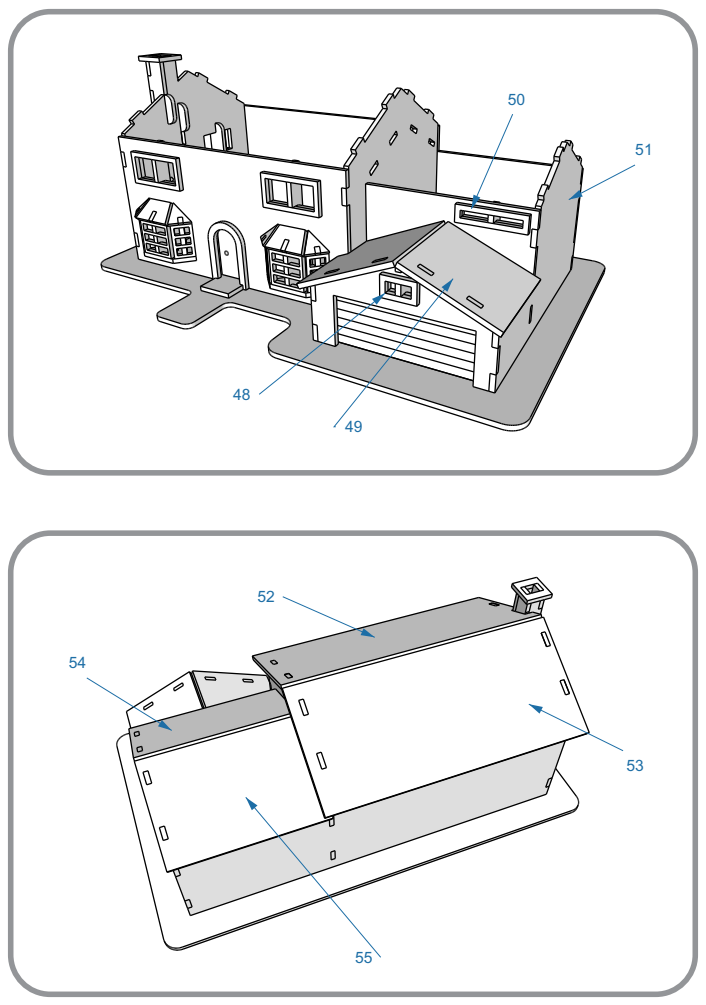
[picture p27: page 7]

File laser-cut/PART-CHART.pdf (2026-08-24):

# Simpsons House — part identification chart

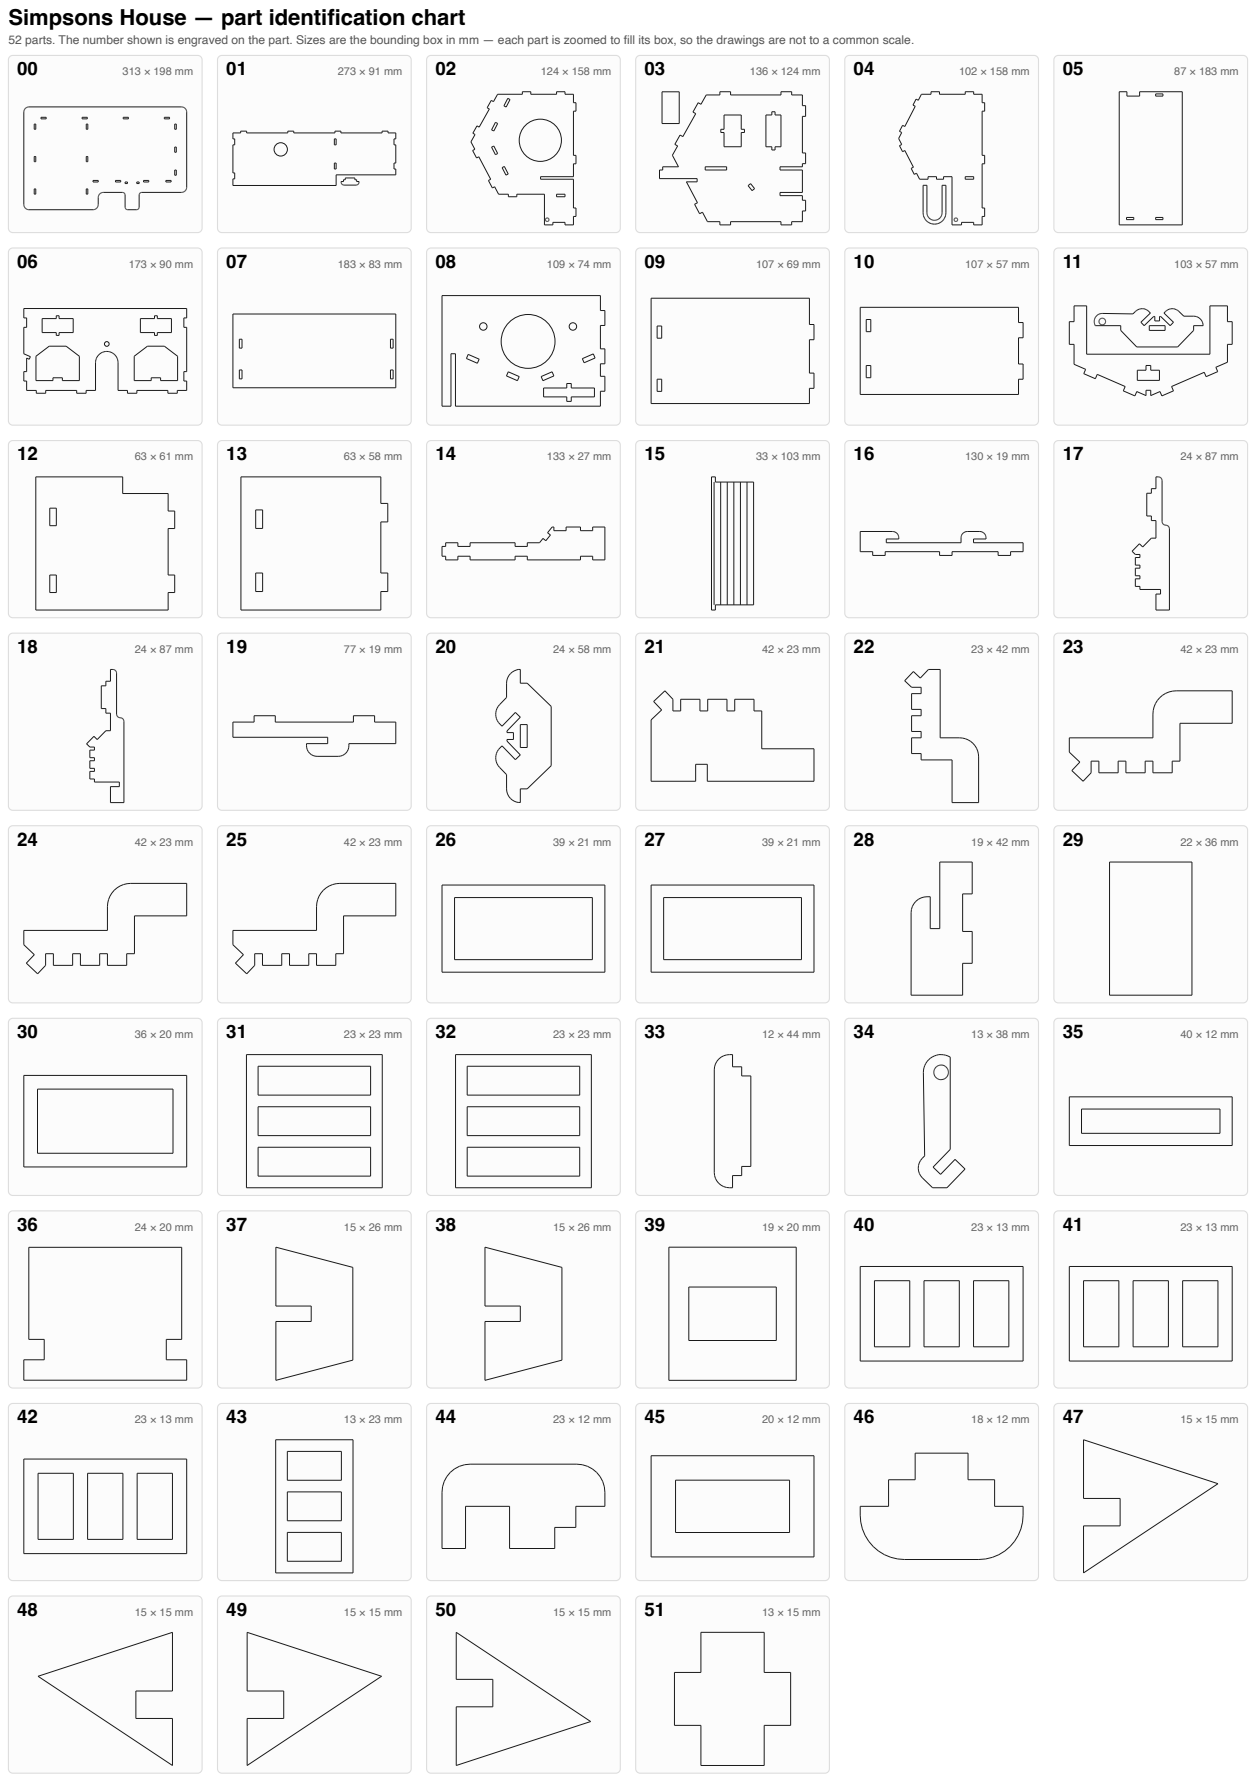
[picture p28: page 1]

52 parts. The number shown is engraved on the part. Sizes are the bounding box in mm — each part is zoomed to fill its box, so the drawings are not to a common scale.

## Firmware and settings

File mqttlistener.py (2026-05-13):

#!/usr/bin/env python3
"""
Simpson's House MQTT Listener and GPIO Controller
==================================================
This Python script runs on the Raspberry Pi and does two things:
  1. Listens for commands sent from the iPad app over the network (via MQTT)
  2. Controls the real hardware (LED, garage servo, front door servo) using the Pi's GPIO pins

TEACHING: Think of this script as the "butler" of the smart house.
The iPad app shouts orders ("turn the light on!") and this script
physically carries them out by sending electrical signals to the hardware.

HOW IT ALL CONNECTS:
  iPad App  →  WiFi/WebSocket  →  Mosquitto (MQTT broker on Pi)  →  this script  →  GPIO pins  →  Hardware
"""

import paho.mqtt.client as mqtt  # Library that speaks the MQTT protocol
import RPi.GPIO as GPIO           # Library that controls the Pi's physical pins
import time                       # Used to add pauses (e.g. while servo moves)
import logging                    # Used to print status messages to the terminal
import json                       # Used to format status updates as JSON (structured text)
import signal                     # Used to catch Ctrl+C and shutdown cleanly
import sys                        # Used to exit the program
from datetime import datetime     # Used to add timestamps to log messages

# =============================================================================
# SECTION 1: CONFIGURATION
# =============================================================================
# TEACHING: These are all the settings in one place. Changing a number here
# changes how the whole program behaves. This is good practice — never
# scatter magic numbers throughout your code.

# GPIO pin assignments — these match the physical wires you plugged in.
# BCM numbering means we use the chip's numbers (GPIO 17), NOT the
# board's physical pin positions (which would be pin 11 for GPIO 17).
LIGHT_PIN        = 17   # Living Room Light (LED + 220Ω resistor on GPIO 17)
GARAGE_SERVO_PIN = 27   # Garage Door Servo signal wire
SERVO_PIN        = 23   # Front Door Servo signal wire

# MQTT broker address — "localhost" means "on this same Raspberry Pi".
# The broker is a separate program (Mosquitto) that routes messages.
BROKER_HOST = "localhost"
BROKER_PORT = 1883   # Standard MQTT port (TCP)
KEEPALIVE   = 60     # Send a heartbeat ping every 60 seconds so the connection stays alive

# TEACHING: MQTT uses "topics" like channels on a walkie-talkie.
# The iPad publishes a message to a topic, and this script subscribes to the same
# topic to receive it. Both sides must use the EXACT same topic string.
TOPIC_LIGHT  = "home/light"    # iPad sends "ON" or "OFF" here
TOPIC_GARAGE = "home/garage"   # iPad sends "OPEN" or "CLOSE" here
TOPIC_DOOR   = "home/door"     # iPad sends "ON" or "OFF" here

# Topics this script publishes status back to the iPad on:
TOPIC_STATUS = "home/status"   # Full JSON snapshot of all device states
TOPIC_SYSTEM = "home/system"   # System info (version, GPIO pins used, etc.)

# TEACHING: Python dictionaries are great for tracking state.
# This keeps track of whether each device is currently ON or OFF.
# True = on/open, False = off/closed
device_states = {
    "light":  False,
    "garage": False,
    "door":   False
}

# These are set up later in main() — we use "global" to share them
# between functions without passing them as parameters every time.
client           = None  # The MQTT client object
GARAGE_SERVO_PWM = None  # PWM controller for the garage door servo
SERVO_PWM        = None  # PWM controller for the front door servo

# =============================================================================
# SECTION 2: LOGGING
# =============================================================================
# TEACHING: Instead of using print(), professional code uses a logging
# library. It automatically adds timestamps and severity levels (INFO,
# WARNING, ERROR) so you can filter messages and understand what went wrong.

logging.basicConfig(
    format="%(asctime)s [%(levelname)s] Simpson's House: %(message)s",
    level=logging.INFO,
    handlers=[logging.StreamHandler(sys.stdout)]
)
logger = logging.getLogger(__name__)

# =============================================================================
# SECTION 3: GPIO SETUP
# =============================================================================
# TEACHING: Before you can use a GPIO pin you must:
#   1. Tell the Pi which numbering scheme you're using (BCM vs BOARD)
#   2. Tell each pin whether it is an INPUT (reading a sensor) or
#      OUTPUT (driving a component)
#   3. Set its initial state (HIGH = 3.3V, LOW = 0V / GND)

def setup_gpio():
    """
    Configure all GPIO pins used by Simpson's House.

    TEACHING: This function runs once at startup. Think of it like
    plugging appliances into sockets — you do it once, then use them.
    """
    logger.info("🏠 Initializing Simpson's House GPIO...")

    GPIO.setmode(GPIO.BCM)      # Use BCM chip numbers (matches our LIGHT_PIN = 17 etc.)
    GPIO.setwarnings(False)     # Suppress "pin already in use" warnings on restart

    # Set up the light pin as an output, starting LOW (off)
    GPIO.setup(LIGHT_PIN, GPIO.OUT, initial=GPIO.LOW)

    # Set up both servo signal pins as outputs, starting LOW
    GPIO.setup(GARAGE_SERVO_PIN, GPIO.OUT, initial=GPIO.LOW)
    GPIO.setup(SERVO_PIN, GPIO.OUT, initial=GPIO.LOW)

    # TEACHING: PWM = Pulse Width Modulation. Instead of just HIGH or LOW,
    # PWM rapidly switches the pin on/off at a set frequency. The ratio of
    # on-time to off-time (duty cycle) controls the servo's angle.
    # 50 Hz is the standard frequency for hobby servo motors.
    global GARAGE_SERVO_PWM, SERVO_PWM
    GARAGE_SERVO_PWM = GPIO.PWM(GARAGE_SERVO_PIN, 50)  # 50 Hz PWM on the garage servo pin
    GARAGE_SERVO_PWM.start(0)                            # Start with 0% duty cycle (servo off)
    SERVO_PWM = GPIO.PWM(SERVO_PIN, 50)                 # 50 Hz PWM on the front door servo pin
    SERVO_PWM.start(0)                                   # Start with 0% duty cycle (servo off)

    logger.info(f"💡 Light pin: GPIO {LIGHT_PIN}")
    logger.info(f"🚗 Garage servo pin: GPIO {GARAGE_SERVO_PIN}")
    logger.info(f"🚪 Front door servo pin: GPIO {SERVO_PIN}")


def set_servo_angle(pwm, angle: int, label: str = "Servo") -> bool:
    """
    Move a servo motor to an angle between 0 and 180 degrees.

    TEACHING: A servo motor has a built-in gearbox and position sensor.
    You tell it WHERE to go (as an angle), not how to get there.
    The duty cycle formula maps 0° → 2% and 180° → 12%.

    Why 2% and 12%? That's the standard pulse width range (1ms–2ms)
    at 50 Hz that SG90-type hobby servos understand.

    This function is shared by both the garage door and the front door servos —
    we just pass in the correct PWM object (GARAGE_SERVO_PWM or SERVO_PWM).
    """
    try:
        if not 0 <= angle <= 180:
            logger.error(f"Invalid servo angle: {angle}. Must be 0-180.")
            return False

        # Convert the 0-180° range into the 2-12% duty cycle range
        duty = (angle / 180.0) * 10 + 2
        pwm.ChangeDutyCycle(duty)
        time.sleep(0.8)            # Wait 0.8 seconds for the servo to physically move
        pwm.ChangeDutyCycle(0)     # Stop sending pulses to prevent jitter/humming

        logger.info(f"🔧 {label} → {angle}°")
        return True

    except Exception as e:
        logger.error(f"❌ Servo control failed ({label}): {e}")
        return False


# =============================================================================
# SECTION 4: MQTT EVENT HANDLERS
# =============================================================================
# TEACHING: MQTT uses an "event-driven" design. Instead of your code
# constantly checking "has a message arrived?", the library calls these
# callback functions FOR you whenever a specific event happens.
# This is sometimes called the "observer pattern".

def on_connect(client, userdata, flags, rc):
    """
    Called automatically by the MQTT library once the broker accepts our connection.

    TEACHING: 'rc' is the return code. 0 = success, anything else = failure.
    This is where we subscribe to topics — subscribing AFTER connecting
    ensures we don't miss any messages sent right at startup.
    """
    if rc == 0:
        logger.info("✅ Connected to Mosquitto MQTT broker")

        # Subscribe to the three device control topics
        # TEACHING: Subscribing means "I want to receive any message published to this topic".
        for topic in [TOPIC_LIGHT, TOPIC_GARAGE, TOPIC_DOOR]:
            client.subscribe(topic)
            logger.info(f"📡 Subscribed to: {topic}")

        # Announce that the controller is online
        publish_system_status("online", "Simpson's House controller started")

        # Send the current state of every device so the app can sync its display
        for device, state in device_states.items():
            publish_device_status(device, state)

    else:
        logger.error(f"❌ MQTT connection failed (code={rc}): {get_mqtt_error_message(rc)}")


def on_disconnect(client, userdata, rc):
    """Called automatically when the connection to the broker is lost."""
    if rc != 0:
        logger.warning(f"⚠️  Unexpected MQTT disconnection (code={rc})")
    else:
        logger.info("📡 MQTT disconnected cleanly")


def on_message(client, userdata, msg):
    """
    Called automatically whenever a message arrives on any subscribed topic.

    TEACHING: This is the heart of the backend. The flow is:
      1. Decode the raw bytes into a readable string
      2. Work out WHICH device the message is for (based on the topic)
      3. Check the command is valid (ON/OFF/OPEN/CLOSE)
      4. Call the matching hardware control function
      5. Publish the new status back to the app so the UI updates

    Think of this function as the call-centre operator — every command
    from the iPad comes through here first.
    """
    try:
        topic   = msg.topic
        payload = msg.payload.decode().strip().upper()  # e.g. b"on" → "ON"

        logger.info(f"📨 Command received: {topic} → {payload}")

        success       = False
        device_name   = ""
        command_state = None
        device_key    = topic.split('/')[-1]  # "home/light" → "light"

        # ── Route by topic ──────────────────────────────────────────────────
        # TEACHING: Each branch maps a topic to a device and validates the
        # command. We use a dictionary (valid_commands) to convert the string
        # command ("ON") into a boolean (True) that our functions understand.

        if topic == TOPIC_LIGHT:
            valid_commands = {"ON": True, "OFF": False}
            device_name    = "Living Room Light"
            command_state  = valid_commands.get(payload)  # None if unrecognised
            if command_state is None:
                publish_error(topic, f"Invalid command: {payload}. Use ON or OFF.")
                return
            success = control_light(command_state)

        elif topic == TOPIC_GARAGE:
            valid_commands = {"OPEN": True, "CLOSE": False}
            device_name    = "Garage Door"
            command_state  = valid_commands.get(payload)
            if command_state is None:
                publish_error(topic, f"Invalid command: {payload}. Use OPEN or CLOSE.")
                return
            success = control_garage_door(command_state)

        elif topic == TOPIC_DOOR:
            valid_commands = {"ON": True, "OFF": False}
            device_name    = "Front Door"
            command_state  = valid_commands.get(payload)
            if command_state is None:
                publish_error(topic, f"Invalid command: {payload}. Use ON or OFF.")
                return
            success = control_door(command_state)

        else:
            logger.warning(f"⚠️  Message on unknown topic: {topic}")
            return

        # ── Report result ───────────────────────────────────────────────────
        if success and command_state is not None:
            device_states[device_key] = command_state       # Update our state tracker
            publish_device_status(device_key, command_state) # Tell the app what changed
            logger.info(f"✅ {device_name} command executed successfully")
        else:
            logger.error(f"❌ {device_name} control failed")
            publish_error(topic, "Device control failed")

    except Exception as e:
        logger.error(f"❌ Message handling error: {e}")
        publish_error(msg.topic, f"Processing error: {str(e)}")


# =============================================================================
# SECTION 5: DEVICE CONTROL FUNCTIONS
# =============================================================================
# TEACHING: Each function here controls ONE physical device. They all follow
# the same pattern: try to do the action, log what happened, return True/False
# so the caller knows if it worked. This makes them easy to test in isolation.

def control_light(state: bool) -> bool:
    """
    Turn the living room LED on or off.

    TEACHING: GPIO.HIGH sends 3.3V to the pin. That voltage flows through
    the 220Ω resistor (which limits the current so the LED doesn't burn out)
    and then through the LED, causing it to emit light.
    GPIO.LOW sets the pin to 0V (GND), so no current flows and the LED goes off.
    """
    try:
        GPIO.output(LIGHT_PIN, GPIO.HIGH if state else GPIO.LOW)
        logger.info(f"💡 Living Room Light → {'ON' if state else 'OFF'}")
        return True
    except Exception as e:
        logger.error(f"❌ Light control error: {e}")
        return False


def control_garage_door(open_door: bool) -> bool:
    """
    Open or close the garage door using the servo motor.

    TEACHING: The servo understands angles, not on/off.
    We map "open" to 90° and "closed" to 0°.
    Both the garage door and front door use the same type of servo —
    we just call set_servo_angle() with the correct PWM object for each.
    You can adjust these angles to match how your servo is physically mounted.
    """
    try:
        angle   = 90 if open_door else 0  # OPEN = 90°, CLOSED = 0°
        success = set_servo_angle(GARAGE_SERVO_PWM, angle, label="Garage Door Servo")
        if success:
            logger.info(f"🚗 Garage Door → {'OPEN (90°)' if open_door else 'CLOSED (0°)'}")
        return success
    except Exception as e:
        logger.error(f"❌ Garage door error: {e}")
        return False


def control_door(state: bool) -> bool:
    """
    Open or close the front door servo.

    TEACHING: The servo understands angles, not on/off.
    We map the "open" concept to 90° and "closed" to 0°.
    You can change these angles to match how your servo is physically mounted.
    """
    try:
        angle   = 90 if state else 0  # OPEN = 90°, CLOSED = 0°
        success = set_servo_angle(SERVO_PWM, angle, label="Front Door Servo")
        if success:
            logger.info(f"🚪 Front Door → {'OPEN (90°)' if state else 'CLOSED (0°)'}")
        return success
    except Exception as e:
        logger.error(f"❌ Door control error: {e}")
        return False


# =============================================================================
# SECTION 6: MQTT PUBLISHING (sending data BACK to the iPad)
# =============================================================================
# TEACHING: MQTT is bi-directional. This section handles the Pi → iPad direction.
# After we carry out a command, we publish the new device state so the app's
# UI can update to reflect what actually happened on the hardware.

def publish_device_status(device: str, status: bool):
    """
    Publish the current state of a device back to the iPad app.

    TEACHING: 'retain=True' tells the Mosquitto broker to remember the last
    message on this topic. If the app reconnects later it will immediately
    receive the last known state without having to ask for it.
    """
    try:
        # Convert boolean to the string the app expects
        if device == "garage":
            status_msg = "OPEN" if status else "CLOSED"
        else:
            status_msg = "ON" if status else "OFF"

        client.publish(f"home/{device}/status", status_msg, retain=True)

        # Publish an overall snapshot of all device states
        system_status = {
            "timestamp":  datetime.now().isoformat(),
            "devices":    device_states.copy(),
            "controller": "online"
        }
        client.publish(TOPIC_STATUS, json.dumps(system_status), retain=True)

    except Exception as e:
        logger.error(f"❌ Status publish error: {e}")


def publish_system_status(status: str, message: str = ""):
    """Publish the overall system information (version, pin layout, etc.)."""
    try:
        system_info = {
            "status":       status,
            "timestamp":    datetime.now().isoformat(),
            "message":      message,
            "version":      "4.0",
            "controller":   "Simpson's House GPIO Controller",
            "gpio_pins": {
                "light":         LIGHT_PIN,
                "garage_servo":  GARAGE_SERVO_PIN,
                "door_servo":    SERVO_PIN
            }
        }
        client.publish(TOPIC_SYSTEM, json.dumps(system_info), retain=True)
    except Exception as e:
        logger.error(f"❌ System status publish error: {e}")


def publish_error(topic: str, error_msg: str):
    """
    Publish an error description to a dedicated error topic.

    TEACHING: Publishing errors to a separate topic (e.g. home/light/error)
    means the app can subscribe to those topics and display the error in the
    UI without mixing error messages with normal status updates.
    """
    try:
        error_info = {
            "error":     error_msg,
            "timestamp": datetime.now().isoformat(),
            "topic":     topic
        }
        client.publish(f"{topic}/error", json.dumps(error_info))
    except Exception as e:
        logger.error(f"❌ Error publish failed: {e}")


# =============================================================================
# SECTION 7: UTILITY FUNCTIONS
# =============================================================================

def get_mqtt_error_message(rc: int) -> str:
    """Convert a numeric MQTT return code into a human-readable explanation."""
    return {
        1: "Incorrect protocol version",
        2: "Invalid client identifier",
        3: "Server unavailable",
        4: "Bad username or password",
        5: "Not authorized"
    }.get(rc, f"Unknown error (code {rc})")


# =============================================================================
# SECTION 8: SHUTDOWN HANDLING
# =============================================================================
# TEACHING: When the program receives a kill signal (e.g. you press Ctrl+C,
# or systemd stops the service), we want to:
#   • Stop both servo motors
#   • Turn off all LEDs
#   • Tell the MQTT broker we are going offline
#   • Release the GPIO pins so other programs can use them
# Python's 'signal' module lets us hook into these OS-level events.

def signal_handler(signum, frame):
    """Called by the OS when the program receives SIGINT (Ctrl+C) or SIGTERM."""
    logger.info(f"🛑 Shutdown signal received ({signum}) — stopping gracefully...")
    cleanup_and_exit()


def cleanup_and_exit():
    """Safely shut down all hardware and network connections before exiting."""
    logger.info("🧹 Cleaning up Simpson's House...")

    try:
        GPIO.output(LIGHT_PIN, GPIO.LOW)  # Light off

        if GARAGE_SERVO_PWM:
            GARAGE_SERVO_PWM.stop()  # Stop garage servo PWM signal
        if SERVO_PWM:
            SERVO_PWM.stop()         # Stop front door servo PWM signal

        GPIO.cleanup()               # Release all GPIO pins back to the OS
        logger.info("✅ GPIO cleaned up")

    except Exception as e:
        logger.error(f"❌ GPIO cleanup error: {e}")

    try:
        if client and client.is_connected():
            publish_system_status("offline", "Controller shutting down")
            client.disconnect()
            logger.info("📡 MQTT disconnected")

    except Exception as e:
        logger.error(f"❌ MQTT cleanup error: {e}")

    logger.info("👋 Simpson's House stopped. Goodbye!")
    sys.exit(0)


# =============================================================================
# SECTION 9: ENTRY POINT (main)
# =============================================================================
# TEACHING: In Python, the block `if __name__ == "__main__":` means
# "only run main() when this file is executed directly" (not when it's
# imported by another script). main() is the function that starts everything.
#
# Startup sequence:
#   1. Register signal handlers (so Ctrl+C shuts down cleanly)
#   2. Initialise GPIO pins
#   3. Create and configure the MQTT client
#   4. Connect to the Mosquitto broker
#   5. Enter the event loop (loop_forever) — this blocks here and processes
#      incoming MQTT messages until the program is killed
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

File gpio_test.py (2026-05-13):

#!/usr/bin/env python3
"""
🏠 Simpson's House GPIO Test Script
=====================================
Run this script BEFORE starting the full system to verify every device
is wired correctly. Work through each test one at a time.

Usage:
    python3 gpio_test.py

What to watch for is printed before each test so you know exactly
what physical movement to expect from the hardware.
"""

import RPi.GPIO as GPIO
import time

# GPIO pin assignments (BCM numbering — must match mqttlistener.py)
LIGHT_PIN        = 17
GARAGE_SERVO_PIN = 27   # Garage Door Servo
SERVO_PIN        = 23   # Front Door Servo


def print_divider():
    print("─" * 50)


class SimpsonsHouseGPIOTest:

    def __init__(self):
        print()
        print("🏠 Simpson's House GPIO Test")
        print_divider()
        print("Setting up GPIO pins...")
        GPIO.setmode(GPIO.BCM)
        GPIO.setwarnings(False)

        GPIO.setup(LIGHT_PIN, GPIO.OUT)
        GPIO.setup(GARAGE_SERVO_PIN, GPIO.OUT)
        GPIO.setup(SERVO_PIN, GPIO.OUT)

        self.garage_servo_pwm = GPIO.PWM(GARAGE_SERVO_PIN, 50)  # 50 Hz for servo
        self.garage_servo_pwm.start(0)

        self.servo_pwm = GPIO.PWM(SERVO_PIN, 50)  # 50 Hz for servo
        self.servo_pwm.start(0)

        print("✅ GPIO pins ready")
        print()

    # ── Test 1: LED ──────────────────────────────────────────────────────────

    def test_light(self):
        print("💡 TEST 1/3 — Living Room Light (GPIO 17)")
        print_divider()
        print("   WHAT TO WATCH FOR:")
        print("   → The LED should blink ON and OFF exactly 3 times")
        print("   → Each blink: 0.5 s ON, then 0.5 s OFF")
        print()
        print("   If nothing happens:")
        print("   • Check the LED is the right way around (long leg toward GPIO 17)")
        print("   • Check the resistor is in the circuit (between GPIO 17 and the LED +)")
        print("   • Verify GPIO 17 is on physical pin 11 (run 'pinout' to check)")
        print()

        input("   Press ENTER when you are watching the LED...")
        print()

        for blink in range(1, 4):
            print(f"   Blink {blink}/3 — ON")
            GPIO.output(LIGHT_PIN, 1)
            time.sleep(0.5)
            print(f"   Blink {blink}/3 — OFF")
            GPIO.output(LIGHT_PIN, 0)
            time.sleep(0.5)

        print()
        response = input("   Did the LED blink 3 times? (y/n): ").strip().lower()
        if response == "y":
            print("   ✅ Light test PASSED")
        else:
            print("   ❌ Light test FAILED — check WIRING_GUIDE.md → Device 1")
        print()

    # ── Test 2: Garage Door Servo ─────────────────────────────────────────────

    def set_servo_angle(self, pwm, angle):
        """Move a servo to specified angle (0–180°)."""
        duty = (angle / 180.0) * 10 + 2  # Maps 0–180° to 2–12% duty cycle
        pwm.ChangeDutyCycle(duty)
        time.sleep(0.5)
        pwm.ChangeDutyCycle(0)  # Stop PWM signal to prevent jitter

    def test_garage_servo(self):
        print("🚗 TEST 2/3 — Garage Door Servo (GPIO 27)")
        print_divider()
        print("   WHAT TO WATCH FOR:")
        print("   → The servo arm should move smoothly to 90° (open position)")
        print("   → Hold for half a second")
        print("   → Then sweep back to 0° (closed position)")
        print()
        print("   If the servo twitches but doesn't hold position:")
        print("   • Check the red power wire is connected to 5V (physical pin 2 or 4)")
        print()
        print("   If nothing moves:")
        print("   • Check the signal wire (orange/yellow/white) → GPIO 27 (physical pin 13)")
        print("   • Check the ground wire (brown/black) → Pi GND (physical pin 6 or 14)")
        print()
        print("   If the arm moves the wrong way:")
        print("   • The servo may be mounted upside-down — that is fine for testing")
        print("   • You can flip the physical servo, or swap the angles in control_garage_door()")
        print()

        input("   Press ENTER when you are watching the garage servo arm...")
        print()

        print("   → Moving to 0°  (closed / starting position)...")
        self.set_servo_angle(self.garage_servo_pwm, 0)
        time.sleep(0.5)

        print("   → Moving to 90° (open position)...")
        self.set_servo_angle(self.garage_servo_pwm, 90)
        time.sleep(0.5)

        print("   → Returning to 0° (closed position)...")
        self.set_servo_angle(self.garage_servo_pwm, 0)
        time.sleep(0.3)

        print()
        response = input("   Did the servo arm move to 90° then return to 0°? (y/n): ").strip().lower()
        if response == "y":
            print("   ✅ Garage servo test PASSED")
        else:
            print("   ❌ Garage servo test FAILED — check WIRING_GUIDE.md → Device 2")
        print()

    # ── Test 3: Front Door Servo ─────────────────────────────────────────────

    def test_servo(self):
        print("🚪 TEST 3/3 — Front Door Servo (GPIO 23)")
        print_divider()
        print("   WHAT TO WATCH FOR:")
        print("   → The servo arm should move smoothly to 90° (open position)")
        print("   → Hold for half a second")
        print("   → Then sweep back to 0° (closed position)")
        print()
        print("   If the servo twitches but doesn't hold position:")
        print("   • Check the red power wire is connected to 5V (physical pin 4)")
        print()
        print("   If nothing moves:")
        print("   • Check the signal wire (orange/yellow/white) → GPIO 23 (physical pin 16)")
        print("   • Check the ground wire (brown/black) → Pi GND (physical pin 6)")
        print()
        print("   If the arm moves the wrong way:")
        print("   • The servo may be mounted upside-down — that is fine for testing")
        print("   • You can flip the physical servo, or change the angle in control_door()")
        print()

        input("   Press ENTER when you are watching the front door servo arm...")
        print()

        print("   → Moving to 0°  (closed / starting position)...")
        self.set_servo_angle(self.servo_pwm, 0)
        time.sleep(0.5)

        print("   → Moving to 90° (open position)...")
        self.set_servo_angle(self.servo_pwm, 90)
        time.sleep(0.5)

        print("   → Returning to 0° (closed position)...")
        self.set_servo_angle(self.servo_pwm, 0)
        time.sleep(0.3)

        print()
        response = input("   Did the servo arm move to 90° then return to 0°? (y/n): ").strip().lower()
        if response == "y":
            print("   ✅ Front door servo test PASSED")
        else:
            print("   ❌ Front door servo test FAILED — check WIRING_GUIDE.md → Device 3")
        print()

    # ── Cleanup ──────────────────────────────────────────────────────────────

    def cleanup(self):
        self.garage_servo_pwm.stop()
        self.servo_pwm.stop()
        GPIO.cleanup()
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

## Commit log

2025-06-17 Add MQTT broker instructions and suppress GPIO warnings
    [mqttlistener.py]
2025-09-01 Switch to ULN2003 stepper motor
2026-04-17 Split Swift Playground into separate files by role
    - MQTTClient.swift: networking layer (DO NOT EDIT)
    - Models.swift: DeviceStates model (DO NOT EDIT)
    - ContentView.swift: root layout
    - HeroSectionView, ConnectionStatusCard, DeviceControlsSection,
    DeviceCard, GarageDoorCard, ConnectionPromptView: student UI files
    with CUSTOMIZE scaffold comments, styling stripped
    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
2026-04-17 Add teaching annotations and student guide
    Rewrote mqttlistener.py with 11 labelled sections and TEACHING: comment
    blocks explaining the why behind GPIO, MQTT, stepper sequencing, PWM,
    and event-driven callbacks — not just what the code does.
    Added TEACHING_GUIDE.md covering every frontend Swift file, every backend
    section, a 12-step button-to-LED trace, beginner/intermediate/advanced
    exercises, and an FAQ for common student questions.
2026-04-17 Add detailed wiring guide and improve GPIO test output
    Students were struggling to wire up the LED, stepper motor, and servo.
    Added WIRING_GUIDE.md with component identification diagrams, step-by-step
    connection tables, breadboard ASCII layouts, common mistakes per device,
    and a full pre-boot checklist.
    Rewrote gpio_test.py to print "what to watch for" before each test,
    prompt the student to confirm what they saw, and give targeted fix hints
    per failure. Updated README wiring section with key facts and a link to
    the new guide.
    [gpio_test.py]
2026-05-13 Fix install_ca.sh: replace grep trust store checks with openssl verify
    The previous verification was grepping ca-certificates.crt for the
    string "wirelesstkc" which will never match — PEM bundle data is
    base64-encoded binary, so cert names don't appear as readable text.
    Changes:
    - check_existing_certificate(): use `openssl verify` instead of grep
    - verify_installation(): use `openssl verify` instead of grep; if it
    fails, auto-retry with update-ca-certificates --fresh before giving up
    - update_trust_store(): always use --fresh to avoid the stale-symlink
    "0 added" problem where leftover symlinks from a prior run cause
    update-ca-certificates to skip the cert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
2026-05-13 Replace garage door stepper motor with servo motor (GPIO 27)
    The ULN2003 28BYJ-48 stepper motor lacked the torque needed for the
    garage door. Replaced with an SG90 servo motor on GPIO 27, matching the
    front door servo design (GPIO 23). Both servos now use the same
    set_servo_angle() logic: 0° = closed, 90° = open.
    - mqttlistener.py: remove all stepper infrastructure (STEP_SEQUENCE,
    stepper_step, rotate_stepper, stop_stepper, motor_state, ULN2003
    references); add GARAGE_SERVO_PWM on GPIO 27; update setup_gpio(),
    control_garage_door(), cleanup_and_exit(), publish_system_status(),
    publish_device_status(); bump version to 4.0
    - gpio_test.py: replace stepper test with garage se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
    [gpio_test.py, mqttlistener.py, stepper_test.py]
2026-06-25 Add files via upload
    These are the required Lazer cut pieces for house construction.
    [Simpsons_house_01.dxf, Simpsons_house_02.dxf, Simpsons_house_03.dxf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]
2026-08-05 feat(laser-cut): add nested cut files for the physical model
    Nest the Shapr3D export onto 600x450 mm sheets for a 10-house run:
    11 sheets at 85.5% average utilisation (worst sheet 79.8%), 3 mm between
    parts, 5 mm border.
    The export is 2053 loose LINE entities rather than closed polylines, so
    part identity is reconstructed from endpoint connectivity and holes are
    absorbed into their parent outline. That yields 52 parts per house across
    40 distinct shapes.
    Part numbers go on a separate ENGRAVE layer as single-stroke digits,
    placed at each part's point of maximum clearance from any cut edge so a
    number can never land in a hole or off a concave edge.
    nest.py self-checks every run: no part ove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
    [Simpsons House with precuts.dxf, sheet-01.dxf, sheet-02.dxf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]
2026-08-05 docs: replace stepper motor references with servo throughout
    The garage door moved from a 28BYJ-48 stepper + ULN2003 driver to an SG90
    servo on GPIO 27 in b62fd06, but the docs still described the old design.
    Verified every claim against mqttlistener.py and gpio_test.py.
    README.md
    - Intro, feature list, architecture diagram, prerequisites
    - Wiring quick reference: 6 wires + keyed motor plug -> 3 servo wires
    - Component list: drop ULN2003, 28BYJ-48 and the 9V battery; 2x SG90
    - Safety notes: no external supply needed for two SG90s on Pi 5V
    - Replace the hand-written stepper test with gpio_test.py plus a minimal
    single-servo PWM snippet
    - Swap the ULN2003 troubleshooting block for servo sym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
2026-08-05 fix(laser-cut): stop engraving part numbers on scrap and across cut lines
    Reported after inspecting the sheets: some numbers sat in window openings
    that fall out as waste, and some ran across cut lines.
    Root cause was a regression in labels.py. unary_union() was added to node
    T-junctions before polygonize(), but that makes polygonize return minimal
    FACES rather than simple rings: an outline with a window comes back as an
    annulus plus the window, and the annulus does not contain the window's
    interior points. The nesting-depth test therefore scored the window as
    depth 0 and classified it as material. On part 26 the window face is also
    the larger of the two, so it won max(area) and the number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
    [sheet-01.dxf, sheet-02.dxf, sheet-03.dxf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]
2026-08-12 fix(install_ca): install the FortiGate CA, not the wireless leaf cert
    setup.sh failed at "Upgrading pip and setuptools" on TKC Pis with
    CERTIFICATE_VERIFY_FAILED against pypi.org, piwheels.org and
    files.pythonhosted.org, all of which FortiGate deep-inspects.
    install_ca.sh was downloading wirelesstkc.pem — the 802.1X/RADIUS server
    certificate for wireless.tkc.wa.edu.au. That is a self-signed *leaf*, not
    a CA, so adding it to the trust store did nothing for SSL inspection. The
    actual SSL-inspection CA (O=Fortinet, CN=FG4H0FT924905481) was already
    published at the same server as fortigate.crt and is now used instead.
    Two bugs let this ship as a green run:
    - check_existing_certificate() g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
2026-08-24 feat(laser-cut): add two-house 450mm nest
    [sheet-01.dxf, sheet-02.dxf, sheet-03.dxf]
2026-08-24 feat(laser-cut): restore panel cutouts in all layouts
    [sheet-01.dxf, sheet-02.dxf, sheet-03.dxf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]
2026-09-02 Add servo tuning and extension guides
    SERVO_TUNING_GUIDE.md covers adjusting the front door and garage door
    angles, reversing a servo's direction, and slowing the movement with a
    stepped sweep instead of a single jump.
    EXTENSION_GUIDE.md walks extension students through adding a new device
    end to end: wiring, the eight places it lives in mqttlistener.py and the
    Swift app, and a test-as-you-go order that isolates faults to one layer.
    servo_calibrate.py jogs either servo to any angle interactively so the
    right numbers can be found before editing the listener.
    Also adds a Guides index to the README and a .gitignore for .DS_Store.
    [servo_calibrate.py]
2026-09-02 Move motor work out of the core build into extensions
    The garage door moved from a 28BYJ-48 stepper to an SG90 servo, but stale
    motor references were left behind in the docs. Sanitised so the core build
    describes only the two servos and the LED.
    - Remove home/garage/motor_status from the teaching guide topic table; the
    listener has never published that topic
    - Correct the OPEN/CLOSE explanation, the cleanup description and the FAQ
    wording, which all still described stepper behaviour
    - Drop motor speed, direction reversal and current sensing from the README
    roadmap; these are extension work, not core features
    - Move stepper_test.py to extensions/ and reframe it from "DEPRECATED" to
    e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
    [stepper_test.py]

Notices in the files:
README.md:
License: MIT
